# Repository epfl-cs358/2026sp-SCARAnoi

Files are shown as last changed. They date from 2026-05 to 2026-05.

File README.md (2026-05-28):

<p align="center">
  SCARAnoi logo
</p>

<p align="center">
  A SCARA robotic arm designed to solve the Tower of Hanoi using computer vision.
</p>

<p align="center">
  
  
  
  
</p>

# SCARA Arm - Solving Hanoi Tower

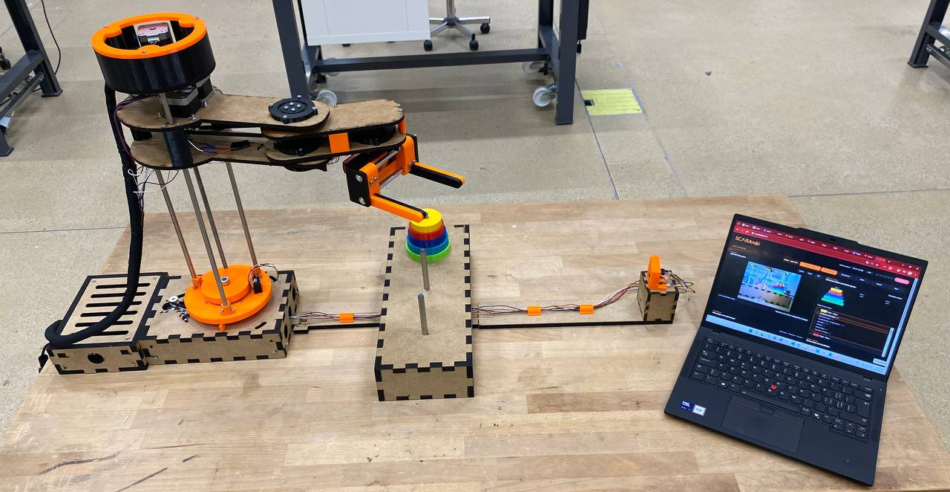
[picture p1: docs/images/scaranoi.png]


The SCARAnoi project aims to design and build a SCARA robot arm capable of solving the Tower of Hanoi problem using computer vision and autonomous manipulation.

The system combines a mechanically designed SCARA arm, a vertical motion axis, a parallel-jaw gripper, a Hanoi platform with three pegs and multiple disks, and a camera-based detection pipeline. The robot detects the position and size of the disks, determines the current configuration of the puzzle, computes the required sequence of moves, and executes the corresponding pick-and-place actions. It is designed to solve standard Tower of Hanoi configurations and to handle intermediate or non-standard configurations by recomputing the solution from the detected state.

Beyond the final demo, the project is meant to be reusable and extensible. The mechanical subsystems, perception pipeline, and motion control logic are separated as much as possible so that anyone can improve individual parts of the project without redesigning the entire system from scratch.

Enjoy building!

# Table of Contents

- [Autonomous Hanoi Solving](#autonomous-hanoi-solving)
- [How to Build](#how-to-build)
  - [Prerequisites](#prerequisites)
- [Hardware](#hardware)
  - [Base](#base)
  - [Arm](#arm)
  - [Gripper](#gripper)
  - [Hanoi Platform and Camera Support](#hanoi-platform-and-camera-support)
- [Electronics](#electronics)
- [Software](#software)
  - [Running the Interface](#running-the-interface)
  - [Browser Interface](#browser-interface)
  - [ESP32 Firmware](#esp32-firmware)
  - [Arduino Firmware](#arduino-firmware)
- [Motion](#motion)
  - [Shoulder and Elbow Motion](#shoulder-and-elbow-motion)
  - [Z-Axis Motion](#z-axis-motion)
  - [Gripper Motion](#gripper-motion)
  - [Homing and Limits](#homing-and-limits)
- [Computer Vision](#computer-vision)
- [Hanoi Algorithm](#hanoi-algorithm)
- [Autonomous Operation](#autonomous-operation)
- [Manual Control](#manual-control)
- [Full Mechanical BOM](#full-mechanical-bom)
- [Top contributors](#top-contributors)

# Autonomous Hanoi Solving

This video shows the SCARAnoi robot solving the Tower of Hanoi problem autonomously. The system detects the initial disk configuration, computes the sequence of moves, and commands the SCARA arm to pick and place the disks according to the rules of the puzzle.

[Demo video](https://youtu.be/Ctyt3jcGtlI)

# How to Build

## Prerequisites

Before starting the build, make sure you have access to the fabrication tools needed for both the mechanical structure and the electronics. SCARAnoi is not only a 3D-printed robot: it also uses laser-cut MDF parts, rods, bearings, belts, motors, wiring, and embedded electronics. A small mechanical workshop setup is therefore very useful.

### 3D Printer

A 3D printer is needed for most of the custom mechanical parts of the robot. This includes parts of the SCARA arm, the gripper frame, the racks and pinion, the jaw holders, the jaws, the Hanoi disks, pulley adapters, spacers, and other small mechanical interfaces.

Most of the 3D-printed parts of SCARAnoi were made in PETG. TPU was used only for the side contact pieces of the gripper jaws. These softer pieces improve contact with the disks and help prevent slipping during pick-and-place movements.

### Laser Cutter

A laser cutter is required for the flat MDF structure of the robot. 

Make sure the MDF thickness matches the design files. If the material thickness is different, the slots may become too loose or too tight and the assembly may need to be adjusted.

### Soldering Equipment

Soldering equipment is needed for the electrical part of the robot. The system includes stepper motors, limit switches, an ESP32-CAM, a servo motor, buck converters, an Arduino Mega, and a RAMPS 1.4 board.

Heat-shrink tubing, connectors, and proper cable management are strongly recommended to avoid loose contacts, short circuits, or communication issues between the ESP32 and the Arduino.

### Mechanical Tools

Basic mechanical tools are required for assembling and adjusting the robot. 

Some parts may need small manual adjustments after fabrication. For example, rods may need to be cut to length, holes may need to be cleaned, and bearings or shafts may need to be fitted carefully.

Pay special attention to the moving assemblies. The Z-axis rods, lead screw, shoulder rotation, belts, pulleys, and gripper racks should move smoothly without excessive friction. Small alignment errors can create noise, wobbling, or missed steps during motion.

### Drill

A drill is useful for preparing or adjusting holes in MDF and 3D-printed parts. 

Be careful when drilling 3D-printed parts. If a hole becomes too large, the part may no longer hold screws, rods, or bearings firmly.

### Computer

A laptop or desktop computer is required to program and control the system. It is used to flash the Arduino firmware, program the ESP32-CAM, run the computer vision code, use the manual control interface, and test the autonomous Hanoi solver.

# Hardware

The hardware of the SCARAnoi project is composed of a SCARA robot arm designed to solve the Tower of Hanoi problem. The system consists of a base, a two-segment arm, a gripper, and a Hanoi platform with camera support.
The structure is divided into four main mechanical assemblies:

- Base
- Arm
- Gripper
- Hanoi Platform and Camera Support

The full mechanical assembly is available here: [Full SCARAnoi assembly design](docs/CAD/Full-Assembly/FinalAssemblySCARAnoi.step).

## Base

Base full assembly : [Base-Assembly-STEP-file](docs/CAD/Base/Assembly/base-assembly.step)

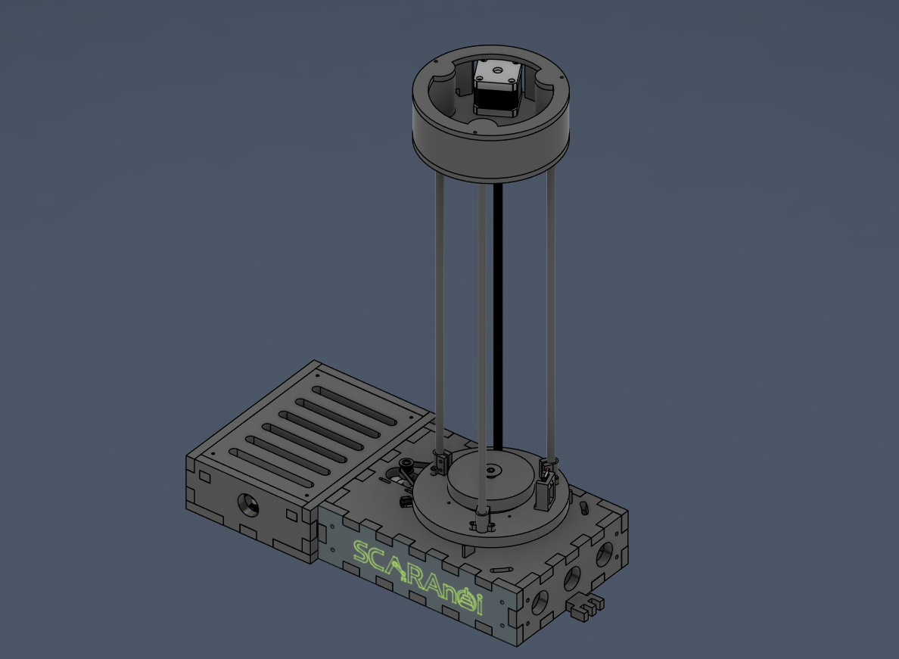
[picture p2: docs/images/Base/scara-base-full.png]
SCARA base full assembly


The base is the main structural support of SCARAnoi. It holds the vertical Z-axis mechanism, supports the rotating shoulder platform, and keeps the robot stable while the arm is moving.

The final version was redesigned as a laser-cut MDF structure with an attached electrical box. This box keeps the electronics accessible during debugging and integration, without needing to open the whole mechanical base every time.

The rotating shoulder platform is mounted on top of the moving Z-axis platform and forms the first rotational joint of the SCARA arm. It is driven by a GT2 belt transmission between a 20-tooth pulley and a 160-tooth pulley. This reduction increases the available torque at the shoulder, which is important because this joint carries the rest of the arm.

### Files to Laser Cut

- [Main base wide side plates x2](docs/CAD/Base/Laser-cut/SideBox-2.dxf)
- [Main base side plate x1](docs/CAD/Base/Laser-cut/SideBox-1.dxf)
- [Main base side plate attached to electrical box x1](docs/CAD/Base/Laser-cut/SideBoxH-1.dxf)
- [Main base top plate x1](docs/CAD/Base/Laser-cut/TopBox.dxf)
- [Main base bottom plate x1](docs/CAD/Base/Laser-cut/BotBox.dxf)
- [Electrical box side plates x2](docs/CAD/Base/Laser-cut/SideElec-2.dxf)
- [Electrical box side plate plug holes x1](docs/CAD/Base/Laser-cut/SideElec-PH.dxf)
- [Electrical box side plate attached to main base box x1](docs/CAD/Base/Laser-cut/SideElecH-1.dxf)
- [Electrical box cover x1](docs/CAD/Base/Laser-cut/TopElec.dxf)
- [Electrical box bottom plate x1](docs/CAD/Base/Laser-cut/BotElec.dxf)
- [Electrical box cover holders x4](docs/CAD/Base/Laser-cut/MountingElec-4.dxf)
- [Upper lift mounting plate x1](docs/CAD/Base/Laser-cut/ShoulderBase.dxf)

### Files to 3D Print

- [Shoulder platform x1](docs/CAD/Base/3D-print/Platform.stl)
- [Shoulder 160 teeths pulley x1](docs/CAD/Base/3D-print/Pulley160T.stl)
- [Shoulder platform cover x1](docs/CAD/Base/3D-print/Cover.stl)
- [Rod clamp supports x3](docs/CAD/Base/3D-print/SmoothRod_Clamp.stl)
- [Limit switch holder base x1](docs/CAD/Base/3D-print/SwitchHolderPlatform.stl)
- [Limit switch holder shoulder x1](docs/CAD/Base/3D-print/SwitchHolderShoulder.stl)
- [Upper lift assembly side panel x1](docs/CAD/Base/3D-print/UpperLiftSide.stl)
- [Upper lift assembly cover plate x1](docs/CAD/Base/3D-print/UpperLiftCover.stl)
- [Mounting blocks x8](docs/CAD/Base/3D-print/Mounting.stl)
- [Limit switch actuators x2](docs/CAD/Base/3D-print/LimitSwitchActuator.stl)

### Bill of Materials

| Part | Quantity | Specification / Notes |
|---|---:|---|
| Smooth rods | 3 | 8 mm diameter, 450 mm length |
| T8 lead screw | 1 | 8 mm diameter, 400 mm length |
| Axial ball bearings | 2 | 50 mm inner diameter, 70 mm outer diameter, 14 mm width |
| Deep groove ball bearing | 1 | 10 mm inner diameter, 30 mm outer diameter, 9 mm width |
| Deep groove ball bearing | 1 | 8 mm inner diameter, 22 mm outer diameter, 7 mm width |
| GT2 belt | 1 | 6mm width, 400 mm length |
| GT2 pulley | 1 | 20-tooth motor pulley (or 16 to have a perfect 1:10 ratio) |
| Shaft coupler | 1 | 5 mm to 8 mm |
| Nema-17 Stepper motor | 2 | For the Z-axis vertical motion and the shoulder rotation|
| MDF sheet 10mm| 1 | For the box |
| MDF sheet 6mm| 1 | For the NEMA motor mounting plate |
| M2.5, M3 and M4 screws | As needed | For mechanical attachments |
| M2.5, M3 and M4S Heat inserts | As needed | For mechanical attachments |
| M10 Screw, Nut and washer | 1 | For fixing the shoulder to the base |
| Limit switches | 4 | For homing the shoulder and Z axis |

### Assembly Procedure

<p align="center">
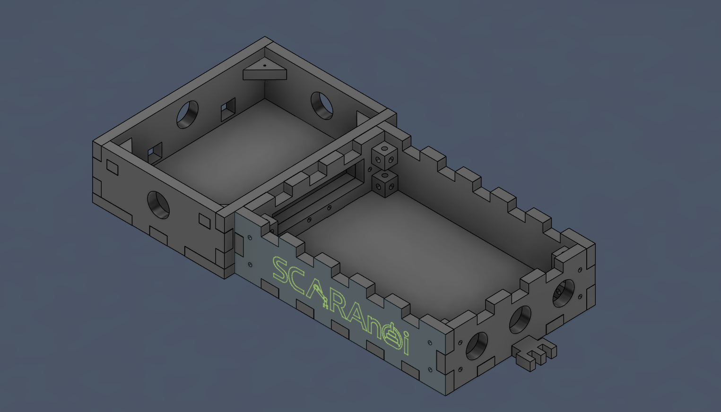
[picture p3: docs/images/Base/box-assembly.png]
Box assembly CAD
  
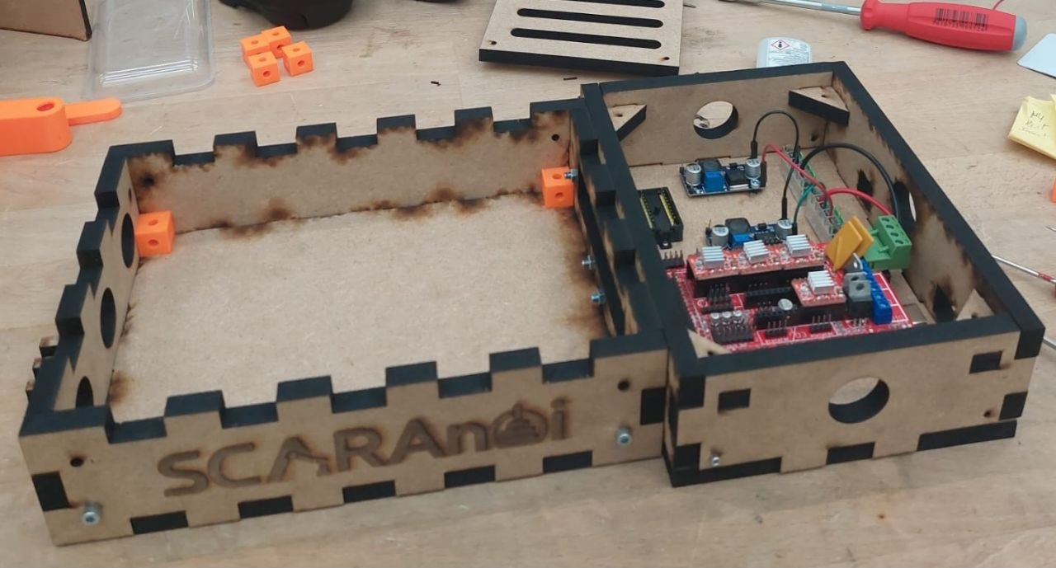
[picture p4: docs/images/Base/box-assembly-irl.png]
Box assembly in real life
  
</p>
Laser cut the MDF parts for the main base and the attached electrical box. Start by assembling the main SCARA base with the finger joints. This base should not be permanently sealed, since some internal parts may still need to be accessed later, for example to tighten the shoulder screw or rearrange wires going through it. To make the side panels removable, we used small 3D-printed mounting blocks inside the base corners. Each block contains two M4S heat-set inserts, one for each adjacent side panel. The blocks are glued to the inner face of a horizontal panel, and the side panels are screwed into them using M4×12 screws. This keeps the base rigid while still allowing it to be opened if needed.

The electrical box is assembled separately. Its side and bottom panels can be glued normally, since it remains accessible from its own opening. Once assembled, attach it to the main base using M4 screws. 

Do not install the top face of the main SCARA base yet. Keeping the top open makes it easier to mount the Z-axis motor, the shoulder platform, the belt transmission, and the screw/nut assembly. If the top face is installed too early, it will probably need to be removed again.

<p align="center">
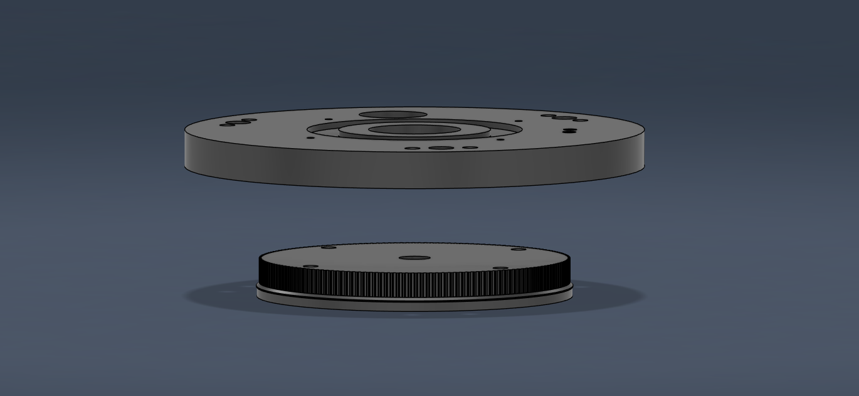
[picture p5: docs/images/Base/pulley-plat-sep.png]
Pulley platform separated
  
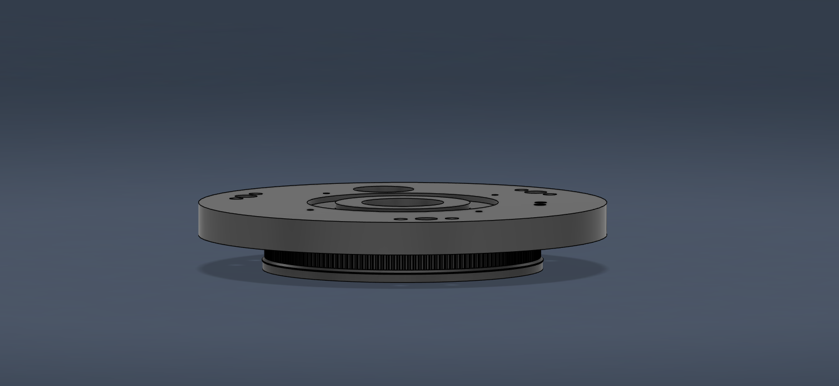
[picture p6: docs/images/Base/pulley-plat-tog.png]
Pulley platform assembled
  
</p> 
Attach the shoulder platform to the 160-tooth pulley using four M2.5×12 screws. The two parts were printed separately to make iteration easier: if one part has a defect or needs a design change, only that part has to be reprinted. Insert four M2.5 heat-set inserts into the pulley, then screw the pulley to the shoulder platform.

Insert two M3 heat-set inserts for each rod clamp into the shoulder platform, for a total of six inserts. Place the three rod clamps and attach them using M3×12 screws.

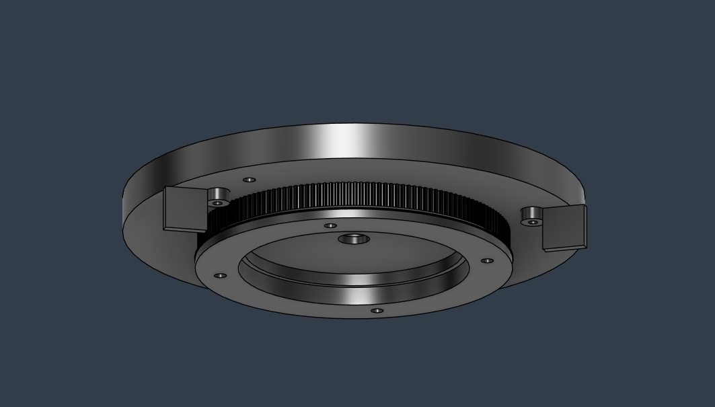
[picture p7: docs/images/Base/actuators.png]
Actuators


The insert holes for the rod clamps pass through the shoulder platform. Flip the platform and reuse two accessible holes to mount the limit switch actuators. Avoid the clamp located on the belt side. Insert the heat-set inserts from the opposite side, then attach the two actuators using one M3×12 screw each.

<p align="center">
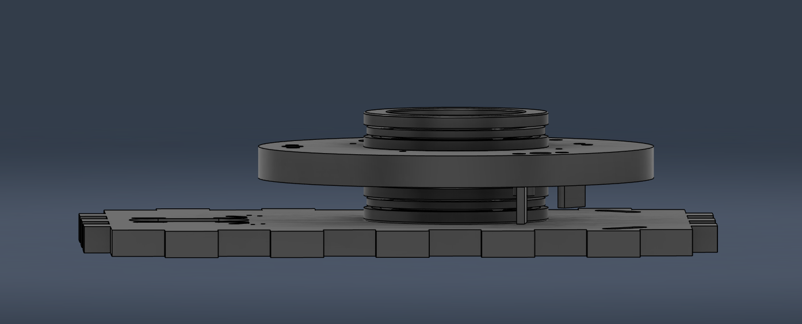
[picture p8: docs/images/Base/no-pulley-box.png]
Box without pulley system
  
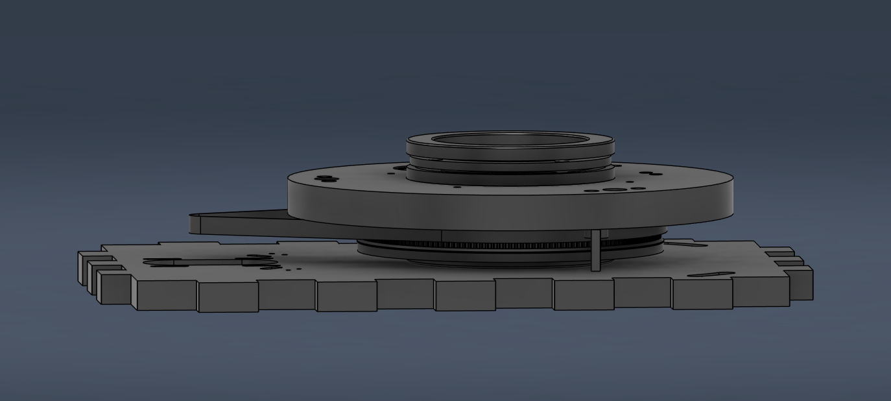
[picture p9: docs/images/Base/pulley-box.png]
Box with pulley system
  
</p>

Next, assemble the shoulder rotation stack. Place one axial ball bearing on the box top face, centered around the 10 mm hole. Before placing the shoulder platform, put the belt around the 160-tooth pulley so it is already in position for the belt transmission. Seat it then on the bearing, making sure the bearing fits correctly into the circular recess at the bottom of the pulley.

<p align="center">
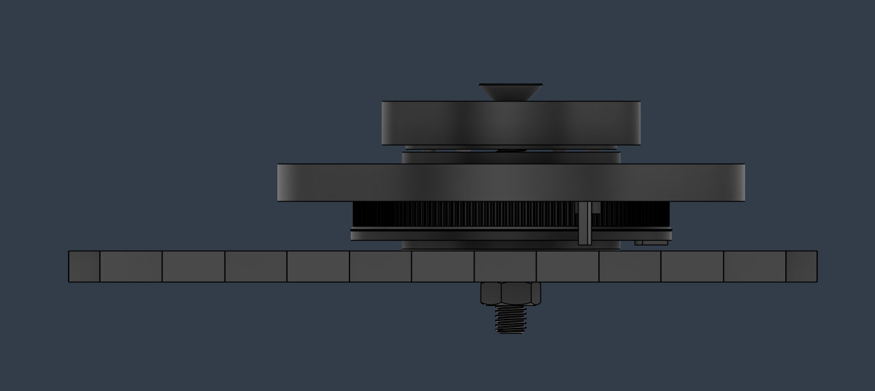
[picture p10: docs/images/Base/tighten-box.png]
Tightened box assembly
  
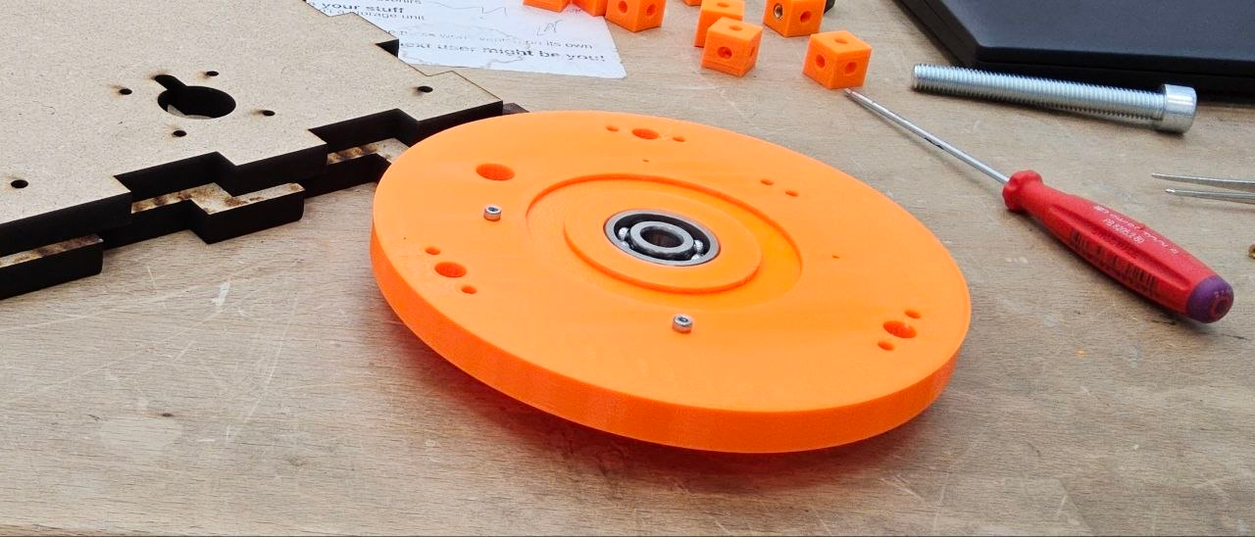
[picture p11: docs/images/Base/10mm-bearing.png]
10 mm bearing
  
</p>

Place the 10x30x9 ball bearing inside the hole at the center top of the platform, then place the second axial bearing in the circular recess on top of it and add the shoulder platform cover. Align the 10 mm holes of the shoulder platform, pulley, bearings, and base top face. Insert the M10 screw from the top, through the full stack, until it comes out under the base top face. Add the washer and M10 nut from below, then tighten carefully. The stack should have no excessive play, but the shoulder must still rotate freely without too much friction.

Once the shoulder stack is assembled, adjust the belt transmission. Place the shoulder NEMA motor in the slots of the base top face and attach the 20-tooth pulley to the motor shaft. Pass the belt around both pulleys, then slide the motor in the slots to set the belt tension. The belt should be tight enough to avoid skipping, but not so tight that it makes rotation difficult. When the tension is correct, fix the motor using four M3×12 screws.

Before closing the main base, it is better to install and wire the three limit switches. This can still be done later, but the top face would need to be removed again. Two limit switches are mounted directly on the main base using M2 screws and nuts. If the screws are not long enough, drill the mounting holes slightly deeper.

The third limit switch is mounted on the shoulder platform. First screw it to its holder using two M2 screws, then attach the holder to the shoulder platform using two M2.5 screws. For this, insert two M2.5 heat-set inserts into the corresponding holes in the shoulder platform. Route the limit switch wires through the nearest hole in the main base, then pass them together with the motor wires through the opening between the main base and the electrical box.

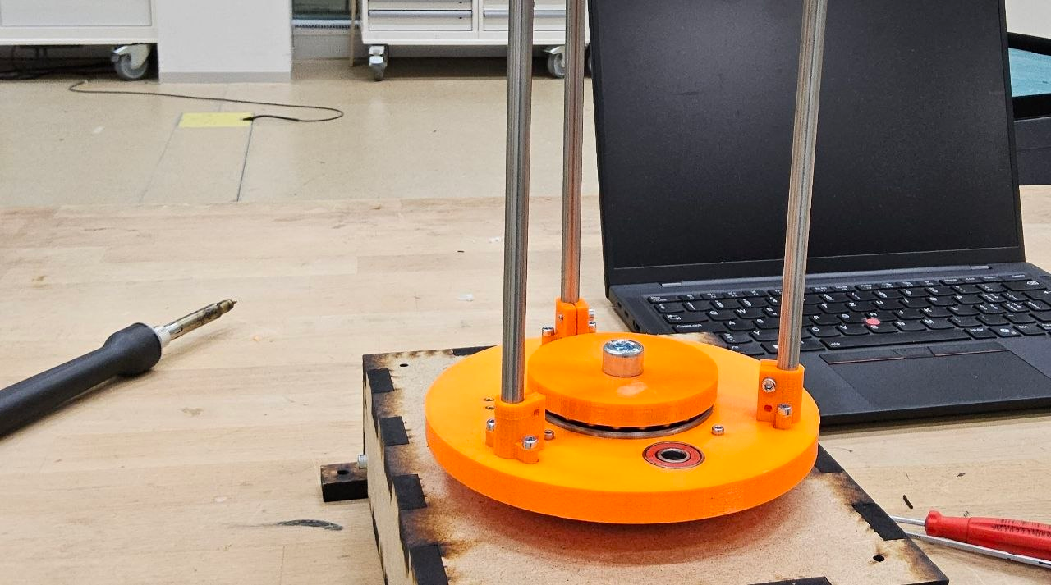
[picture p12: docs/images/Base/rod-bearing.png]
Rod bearing


After this, close the main SCARA base by installing the top face. Then install the three 8 mm smooth rods vertically. Place the 8x22x7 ball bearing into its matching hole in the platform, insert each rod into its clamp support and tighten it using two M3 screws. These rods guide the moving shoulder platform during Z-axis motion and prevent it from tilting, so they should be as parallel as possible. If they are misaligned, the platform may create friction or get stuck.

<p align="center">
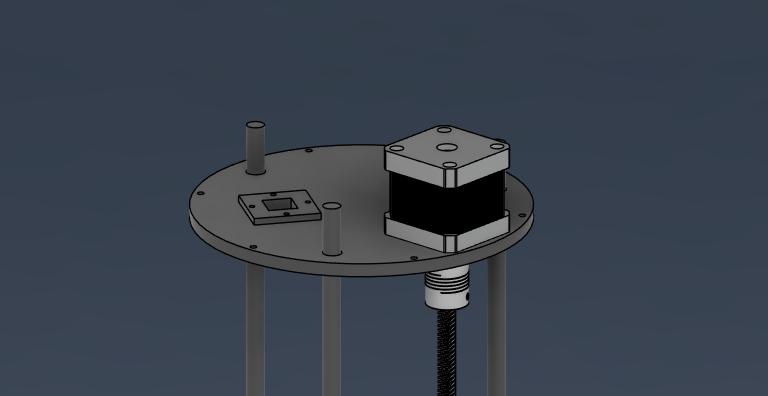
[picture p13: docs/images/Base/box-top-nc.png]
Box top without cover
  
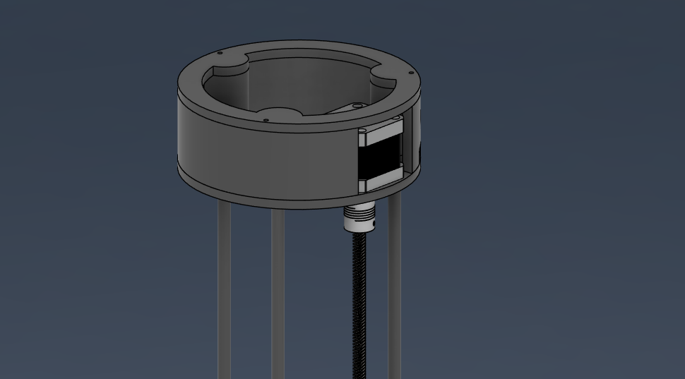
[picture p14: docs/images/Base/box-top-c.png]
Box top with cover
  
</p>

Next, assemble the upper lift. Insert M3 heat-set inserts into the top and bottom screw holes of the upper lift side panel. Screw the side panel to the 6 mm MDF upper lift mounting plate. Place the Z-axis NEMA motor in the corresponding slot, screw it in place, and attach the shaft coupler to the motor shaft. Then screw the upper lift cover plate to the top of the side panel.

Connect the T8 lead screw to the free side of the shaft coupler. Then place the 8x22x7 ball bearing into its matching hole in the platform, insert the three 8 mm smooth rods into their corresponding holes in the upper lift cover plate and finally guide the lead screw through the bearing. 

To mount the arm, the upper lift cover plate will need to be removed temporarily so the arm can be inserted onto the rods.

## Arm

Arm full assembly : [Arm-Assembly-STEP-file](docs/CAD/Arm/Assembly/arm-assembly.step)

The arm is the main kinematic structure of the SCARA robot. It consists of two rigid segments connected by rotational joints. Each joint is driven independently, giving the robot two degrees of freedom for horizontal motion. This allows the gripper to freely reach any object in a radius less than the combined length of the arms.<br>
- The floor and ceiling of each of the arm segments are made using laser-cut 6mm thick MDF. The rest of the parts are made using 3d-printed parts, they include bearing holders, bearing covers, pulleys and pillars.
- Each of the rotation axes (which we named Y for the elbow segment and E for the gripper) is supported by 2 bearings to ensure no undesirable play and proper transmission for the E rotation.
- Each rotation is also limited by 2 limit switches that have approximately an 80 degree angle between them. The effective dead zone can be tuned depending on the piece interfacing with the switches.
- Both rotation axes have a 3.2:1 pulley ratio. This can be changed by printing pulleys with more teeth or choosing the motor pulleys with less teeth.

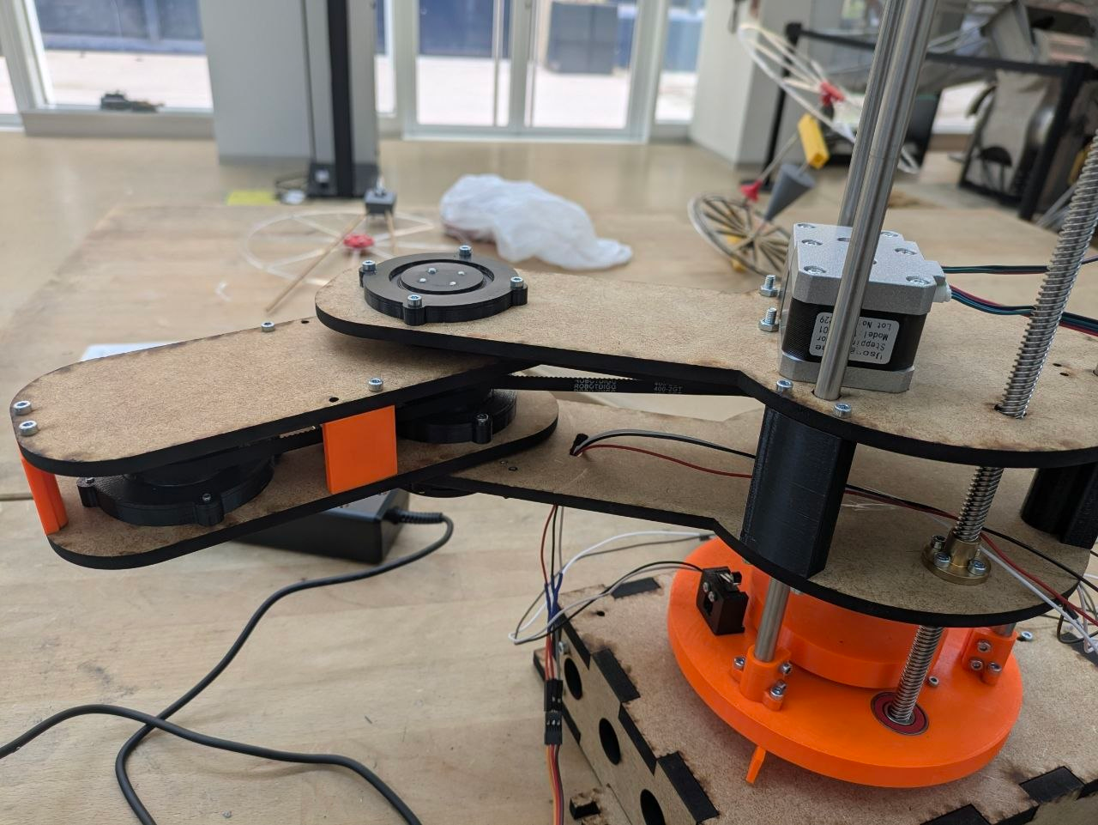
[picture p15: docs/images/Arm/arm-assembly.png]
Arm Assembly


### Files to Laser Cut

- [Inner arm ceiling](docs/CAD/Arm/Laser-cut/inner-arm/inner-ceiling.dxf)
- [Inner arm floor](docs/CAD/Arm/Laser-cut/inner-arm/inner-floor.dxf)
- [Motor holder](docs/CAD/Arm/Laser-cut/inner-arm/motor-holder.dxf)
- [Outer arm ceiling](docs/CAD/Arm/Laser-cut/outer-arm/outer-ceiling.dxf)
- [Outer arm floor](docs/CAD/Arm/Laser-cut/outer-arm/outer-floor.dxf)

### Files to 3D Print

#### Inner arm pieces

- [Inner arm cover 1](docs/CAD/Arm/3D-print/inner-arm/inner-cover1.stl)
- [Inner arm cover 2](docs/CAD/Arm/3D-print/inner-arm/inner-cover2.stl)
- [Inner arm cover 3](docs/CAD/Arm/3D-print/inner-arm/inner-cover3.stl)
- [Inner arm housing cover1](docs/CAD/Arm/3D-print/inner-arm/inner-housing-cover1.stl)
- [Inner arm housing cover2](docs/CAD/Arm/3D-print/inner-arm/inner-housing-cover2.stl)
- [Inner arm housing 1](docs/CAD/Arm/3D-print/inner-arm/inner-housing1.stl)
- [Inner arm housing 2](docs/CAD/Arm/3D-print/inner-arm/inner-housing2.stl)
- [Inner pillar 1](docs/CAD/Arm/3D-print/inner-arm/inner-pillar1.stl)
- [Inner pillar 2](docs/CAD/Arm/3D-print/inner-arm/inner-pillar2.stl)
- [Inner pillar 3](docs/CAD/Arm/3D-print/inner-arm/inner-pillar3.stl)
- [Inner pulley](docs/CAD/Arm/3D-print/inner-arm/inner-pulley.stl)

#### Outer arm pieces

- [Outer arm cover 1](docs/CAD/Arm/3D-print/outer-arm/outer-cover1.stl)
- [Outer arm cover 2](docs/CAD/Arm/3D-print/outer-arm/outer-cover2.stl)
- [Outer arm housing cover1](docs/CAD/Arm/3D-print/outer-arm/outer-housing-cover1.stl)
- [Outer arm housing cover2](docs/CAD/Arm/3D-print/outer-arm/outer-housing-cover2.stl)
- [Outer arm housing 1](docs/CAD/Arm/3D-print/outer-arm/outer-housing1.stl)
- [Outer arm housing 2](docs/CAD/Arm/3D-print/outer-arm/outer-housing2.stl)
- [Outer pillar 1](docs/CAD/Arm/3D-print/outer-arm/outer-pillar1.stl)
- [Outer pillar 2](docs/CAD/Arm/3D-print/outer-arm/outer-pillar2.stl)
- [Outer pillar 3](docs/CAD/Arm/3D-print/outer-arm/outer-pillar3.stl)
- [Outer pulley 1](docs/CAD/Arm/3D-print/outer-arm/outer-pulley1.stl)
- [Outer pulley 2](docs/CAD/Arm/3D-print/outer-arm/outer-pulley2.stl)

### Other Parts

| Part | Quantity | Specification / Notes |
|---|---:|---|
| NEMA 17 stepper motors | 2 | 17hs4401  |
| GT2 aluminium Timing pulley| 2 | 20 Teeth |
| M3 Threaded heat inserts | 12 |  |
| Deep Groove Ball Bearing 6906 / 61906 RS | 4 | 30x47x9mm |
| GT2 6mm wide Timing belt | 2 | 400m long |
| GT2 6mm wide Timing belt | 1 | 350m long |
| LM8UU Linear Bearing | 4 | 8mm |
| TR8 Trapezoidal Nut Brass | 1 | 8mm pitch |

### Assembly Procedure

- Screw the motor holder to the inner arm ceiling using M4 screws and nuts. Then mill the housing holes in the inner arm floor with a drill and milling head, for the purpose of using countersunk screws. Also drill the holes of the microswitch holes about 2mm down (unless you can get M2 screws longer or equal to 14mm).<br>
- For each of the bearings, insert them inside the housing and then put the housing cover on top, then screw these assemblies to their corresponding floor or ceiling. Beware that the lower bearing assembly is upside down and screwed with countersunk screws. Make sure you get the right housing for the bearings, the outer arm housings are slightly taller than the inner arm housings. Also for the assembly with the double pulley, you need to put together the cover pieces of the inner arm first as told next.<br>
- The outer arm ceiling holes that interface with the inner arm need to be drilled to allow the screw heads to fit in, otherwise they rub against the outer arm first pulley, which can prevent the arm from moving slowly. <br>
- Once that is done, you can now screw together the pieces sandwitching the bearings. The inner cover 1 and inner pulley go on the top inner bearing, the inner cover 2 and inner cover 3 go on the bottom inner bearing (they can be held together with friction from the screw fitting in the petg). The outer pulley 2 and outer cover 2 go on the furthest outer bearing, and the outer pulley 1 and outer cover 1 go on the closest outer bearing. This last one has to be screwed with the bearing assembly mentioned earlier.<br>
- Try to put the motor pulley on the second motor shaft only about 10mm in to be aligned with the height of the outer arm pulley. After that try to connect the with a 400mm belt, it might be easier to put the belt around the motor pulley then sliding into the pulley. You can then move the motor to attain desired tightness, then screw it down. <br>
- Finally, you can put heat inserts in the holes of inner and outer pillars. And screw everything where it fits.<br>
- I advise to have the CAD open to check the position of each piece in the full assembly. Some pieces might seem identical but they are not.<br>

## Gripper

Gripper full assembly : [Gripper-Assembly-STEP-file](docs/CAD/Gripper/Assembly/gripper-assembly.step)

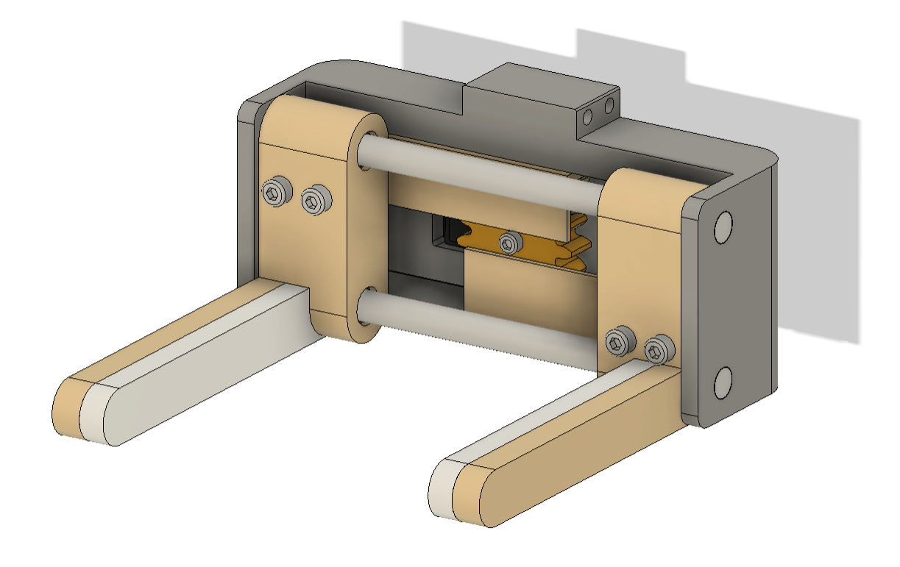
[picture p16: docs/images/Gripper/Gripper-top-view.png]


The gripper is the end-effector (“hand”) of the SCARA arm. It is designed to grasp, hold, transport, and release the Tower of Hanoi disks.

The selected system is a parallel-jaw gripper actuated by a rack-and-pinion mechanism. This design allows both jaws to move symmetrically, which helps keep the disks centered during grasping.

### Files to Laser Cut

No laser-cut parts are required for the gripper.

### Files to 3D Print (using the default PrusaSlicer settings unless specified otherwise)

- [Gripper frame](docs/CAD/Gripper/3D-print/PETG/Frame.stl)
- 2 racks & 1 pinion: [Right Rack](docs/CAD/Gripper/3D-print/PETG/Right-Rack.stl), [Left Rack](docs/CAD/Gripper/3D-print/PETG/Left-Rack.stl), [Pinion](docs/CAD/Gripper/3D-print/PETG/Pinion.stl); Print settings: Vertical Shells > Perimeters = 5
- 2 jaws: [Right Jaw](docs/CAD/Gripper/3D-print/PETG/Right-Jaw.stl), [Left Jaw](docs/CAD/Gripper/3D-print/PETG/Left-Jaw.stl)
- 2 TPU contact layers with disks: [Right-Jaw TPU Layer](docs/CAD/Gripper/3D-print/TPU/TPU-Layer-Right-Jaw.stl), [Left-Jaw TPU Layer](docs/CAD/Gripper/3D-print/TPU/TPU-Layer-Left-Jaw.stl); Print settings: Horizontal Shells > Solid Layers > Top = 0, Bottom = 4 / Infill = 25%

### Other Parts

| Part | Quantity | Specification / Notes |
|---|---:|---|
| DS3230MG servo motor | 1 |  |
| Aluminium guide rods | 2 | 8 mm diameter, 14 cm length |
| LM8UU linear bearings | 4 | 8 mm × 12 mm × 19 mm |
| M4 screws and inserts | 4 each | To attach jaws to racks |
| M3 screws and inserts | 4 each | To attach gripper frame to arm |
| Metallic retaining rings | 4 | 8 mm diameter, serves as an additional safety measure to prevent the rods from sliding out of the frame |

### Assembly Procedure

1) 3D print the main frame, racks, pinion, and jaws in PETG, and print the 2 jaw contact layers in TPU.
2) Glue each TPU contact layer onto its corresponding inner jaw surface using high-strength adhesive.
3) In each jaw, insert 2 LM8UU linear bearings into the dedicated mounting holes.
4) Now that the jaws are ready to be mounted, place the M4 threaded inserts into the dedicated holes of the racks and into the mounting holes at the back of the frame.
5) Mount the servo motor at the rear of the frame using M4 screws.
6) Install the 2 racks inside the internal guiding channels of the frame. Ensure they slide smoothly (lightly sand the channels if needed).
7) Glue the plastic servo hub into the pinion.
8) Now that the servo hub and pinion are attached together, mount the servo hub onto the servo shaft while properly aligning the pinion teeth with the teeth of both racks.
9) Actuate the servo to verify that both racks move symmetrically in opposite directions.
10) Machine circular grooves at both ends of each aluminum guide rod to allow later the 4 retaining rings to be attached securely.
11) Insert the 2 aluminum guide rods through one side only of the frame.
12) Slide both jaws onto the rods through their linear bearings, then pass the rods through the opposite side of the frame.
13) Now make sure that the jaws slide smoothly along the guide rods without excessive friction.
14) Fasten each jaw to its corresponding rack using M4 screws. The inner surfaces of the jaws should remain perfectly parallel to ensure stable and firm gripping of the disks.
15) Attach the 4 metallic retaining rings, one on each side of both rods.
16) Now that the gripper is assembled, test gripping each of the 5 disks with the servo actuated. Verify that the gripper opens sufficiently for the largest disk while still securely gripping the smallest one.
17) Place the 4 M3 threaded inserts into the dedicated mounting holes in the gripper’s top rectangular extrusion.
18) Mount the gripper onto the arm by fitting the rectangular extrusion into the dedicated 3D-printed arm interface and fastening it with M3 screws.

The final assembly should look as follows (with the retaining rings attached on both sides):

<p align="center">
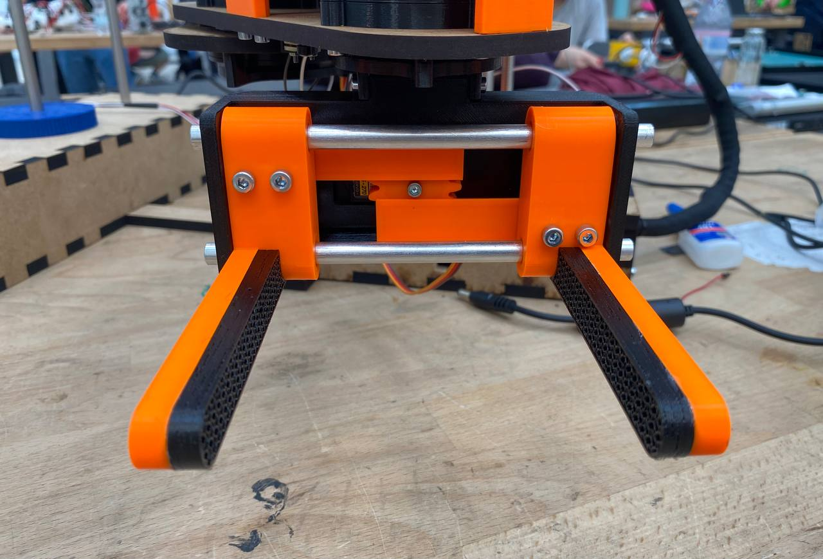
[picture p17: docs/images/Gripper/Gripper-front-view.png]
  
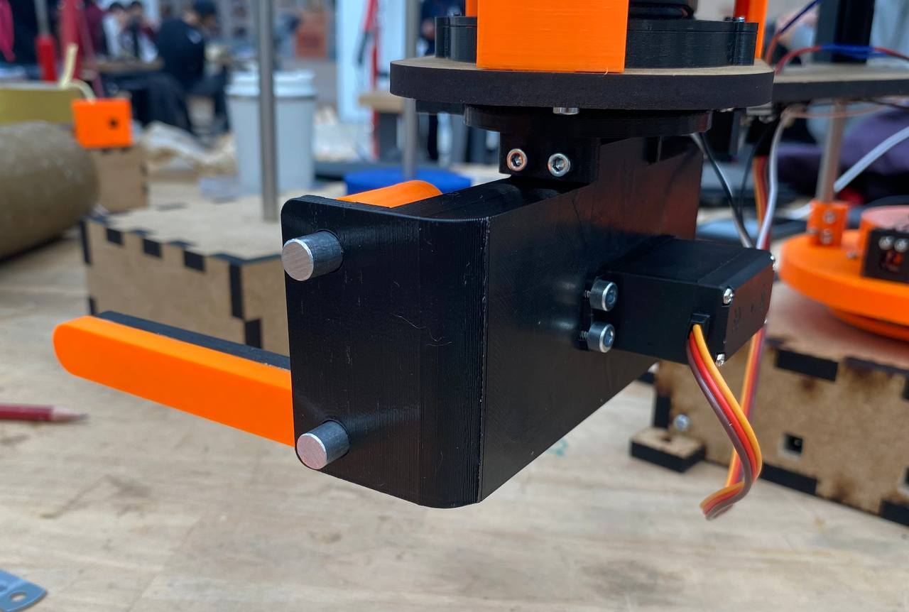
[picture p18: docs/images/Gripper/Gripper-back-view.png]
  
</p>

<p align="center">
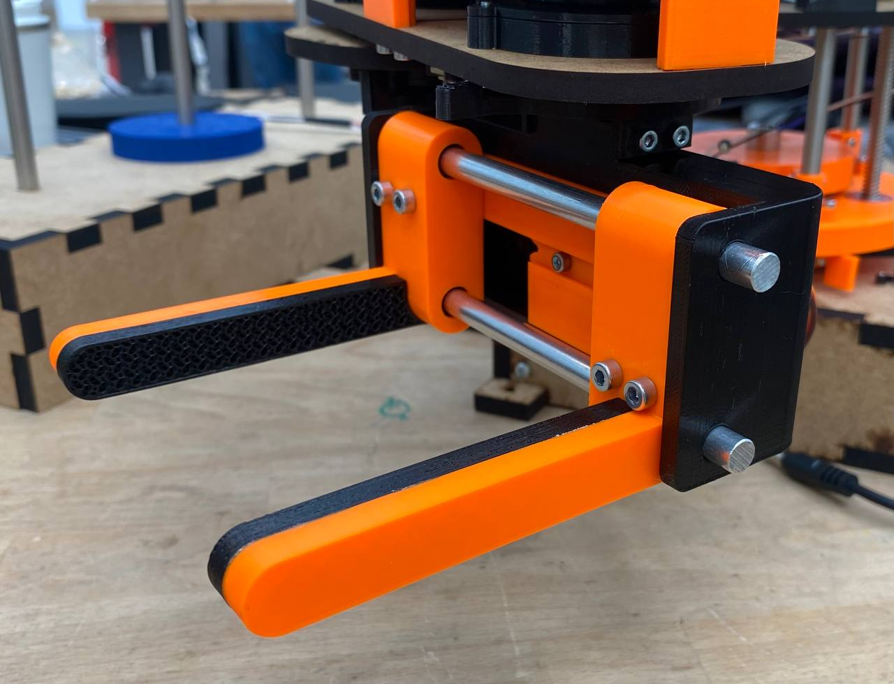
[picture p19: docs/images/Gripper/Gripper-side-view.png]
  
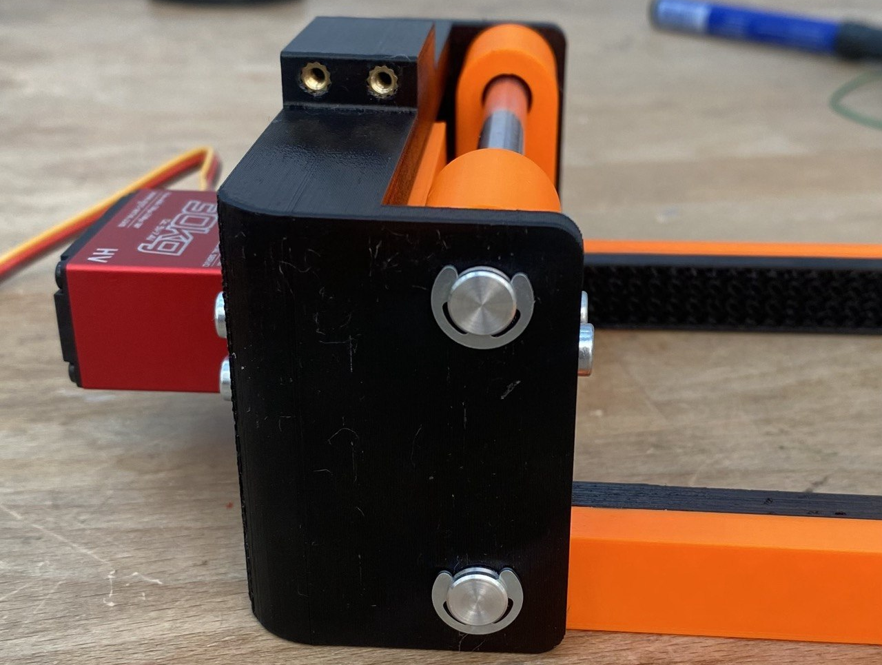
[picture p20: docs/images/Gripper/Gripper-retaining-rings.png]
  
</p>

## Hanoi Platform and Camera Support

Hanoi Platform and Camera Support full assembly : [Full-Assembly-STEP-file](docs/CAD/Hanoi-Platform-Camera-Support/Assembly/HanoiPlatformandCameraSupport.step)

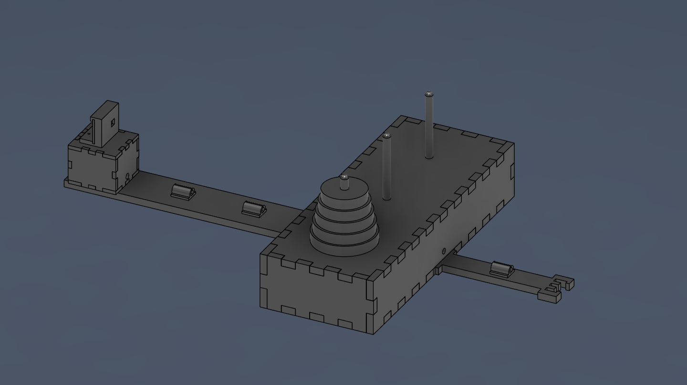
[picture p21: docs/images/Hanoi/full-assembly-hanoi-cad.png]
full assembly hanoi


The Hanoi platform is the working environment of the robot. It holds the three pegs and the disks manipulated by the SCARA arm.

A camera support structure is integrated into the platform to provide a fixed overhead view of the puzzle. This fixed viewpoint helps the computer vision system detect the disk configuration more reliably.

### Files to Laser Cut

- Main Hanoi platform: [Top Box Face](docs/CAD/Hanoi-Platform-Camera-Support/Laser-cut/TopHanoiBox.dxf), [Bottom Box Face](docs/CAD/Hanoi-Platform-Camera-Support/Laser-cut/BottomHanoiBox.dxf), [Big Side Box Face x2](docs/CAD/Hanoi-Platform-Camera-Support/Laser-cut/BigSideHanoiBox.dxf), [Small Side Box Face x2](docs/CAD/Hanoi-Platform-Camera-Support/Laser-cut/SideSmallHanoiBox-2.dxf)
- Camera support box: [Top/Bottom Box Face](docs/CAD/Hanoi-Platform-Camera-Support/Laser-cut/TopBoxCamera-2.dxf), [Side Box Face with no cable holes x2](docs/CAD/Hanoi-Platform-Camera-Support/Laser-cut/SideFaceCameraNH.dxf), [Side Box Face with cable holes x2](docs/CAD/Hanoi-Platform-Camera-Support/Laser-cut/SideFaceCameraH-2.dxf)
- 2 box connectors: [Connector Scara-Hanoi](docs/CAD/Hanoi-Platform-Camera-Support/Laser-cut/LiaisonHanoi-Box.dxf), [Connector Hanoi-Camera](docs/CAD/Hanoi-Platform-Camera-Support/Laser-cut/LiaisonCamera-Hanoi.dxf)

### Files to 3D Print

- 5 Hanoi disks: [Disk 1](docs/CAD/Hanoi-Platform-Camera-Support/3D-print/Disks/Disk1.stl), [Disk 2](docs/CAD/Hanoi-Platform-Camera-Support/3D-print/Disks/Disk2.stl), [Disk 3](docs/CAD/Hanoi-Platform-Camera-Support/3D-print/Disks/Disk3.stl), [Disk 4](docs/CAD/Hanoi-Platform-Camera-Support/3D-print/Disks/Disk4.stl), [Disk 5](docs/CAD/Hanoi-Platform-Camera-Support/3D-print/Disks/Disk5.stl)
- Camera case: [Body](docs/CAD/Hanoi-Platform-Camera-Support/3D-print/Pegs/peg-head-body.stl), [Slider](docs/CAD/Hanoi-Platform-Camera-Support/3D-print/Camera/esp_slider.stl)
- Peg heads x3: [Body](docs/CAD/Hanoi-Platform-Camera-Support/3D-print/Pegs/peg-head-body.stl), [Top](docs/CAD/Hanoi-Platform-Camera-Support/3D-print/Pegs/peg-head-top.stl)
- [Cable Holder](docs/CAD/Hanoi-Platform-Camera-Support/3D-print/Box/cable_management.stl)

### Other Parts

| Part | Quantity | Specification / Notes |
|---|---:|---|
| Rods | 3 | 10 mm diameter, 8 mm inner diameter, used as pegs  |
| ESP32-CAM module | 1 |  |
| M3 Screws| As needed |  |
| MDF sheet| As needeed | We used 2, 10 mm for the hanoi box and connectors and 5mm for the camera box, but dimensions don't really matter|

### Disk Dimensions

The system uses 5 disks. Each disk has a height of 15 mm and a central hole of 14 mm diameter. The disk diameters range from 53 mm to 90 mm.

| Disk number | Diameter |
|---|---|
| 1, smallest | 59 mm |
| 2 | 66 mm |
| 3 | 73 mm |
| 4 | 80 mm |
| 5, largest | 87 mm |

### Assembly Procedure

Laser cut the main platform and the camera support structure from MDF. Assemble the platform using the joints.

Install the three pegs into the platform. The pegs should be spaced 90 mm apart from center to center. Make sure that they are vertical and firmly fixed.

3D print the 5 disks. Each disk should slide freely on the pegs without excessive friction. The 14 mm central hole provides clearance around the 10 mm pegs.

Mount the camera case to its support box, which is itself mounted at the end of the Hanoi-camera connector. This connector keeps the ESP32-CAM at a fixed position relative to the Hanoi pegs, which improves repeatability during computer vision detection.

There are no predefined screw holes in the camera support box so that the camera angle can be adjusted manually during assembly and once the desired angle is found, the screw holes can be drilled directly in the box. Verify that all three pegs and the full disk area are visible in the camera frame.

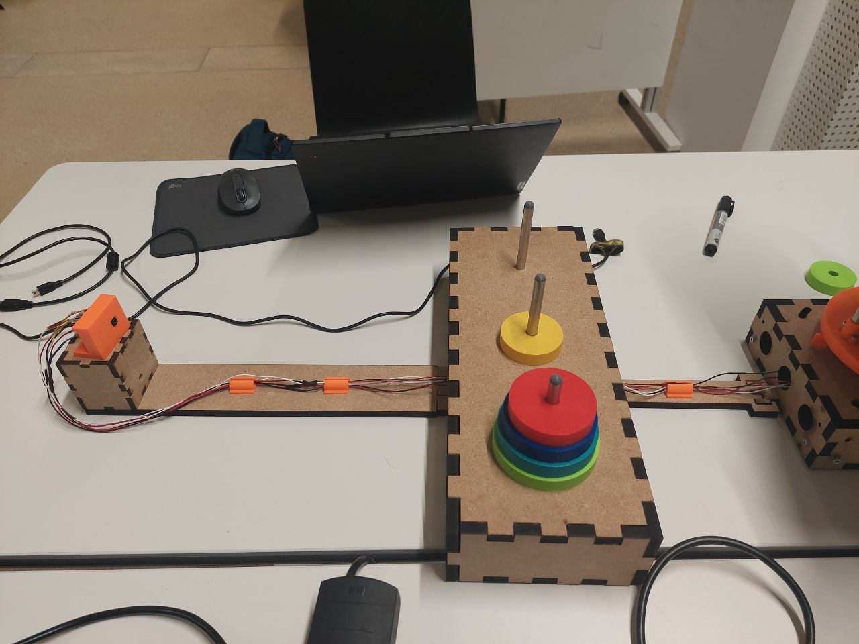
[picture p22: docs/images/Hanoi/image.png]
Hanoi image


# Electronics

The entire system uses a 12V 10A DC power supply, which is plugged into a standard barrel jack. This jack is then wired to two connectors that distribute the power and regroup the common ground for three components: the RAMPS 1.4 board and two LM2596 buck converters. The buck converters are calibrated to regulate 5V and 7V for the EPS32-CAM and DS3230MG servo motor respectively.

The system is centered around an Arduino Mega 2560 with a RAMPS 1.4 board. The port of the Arduino is made accessible in order to upload code to it, while the RAMPS sits on top of it and handles all connections to other components. This includes the four A4988 stepper drivers, the cable to the NEMA 17 stepper motors themselves, the eight limit switches, the servo motor and the 8-channel logic-level converter. This converter is then connected to the ESP32-CAM to allow the serial communication with the Arduino/RAMPS system.

<p align="center">
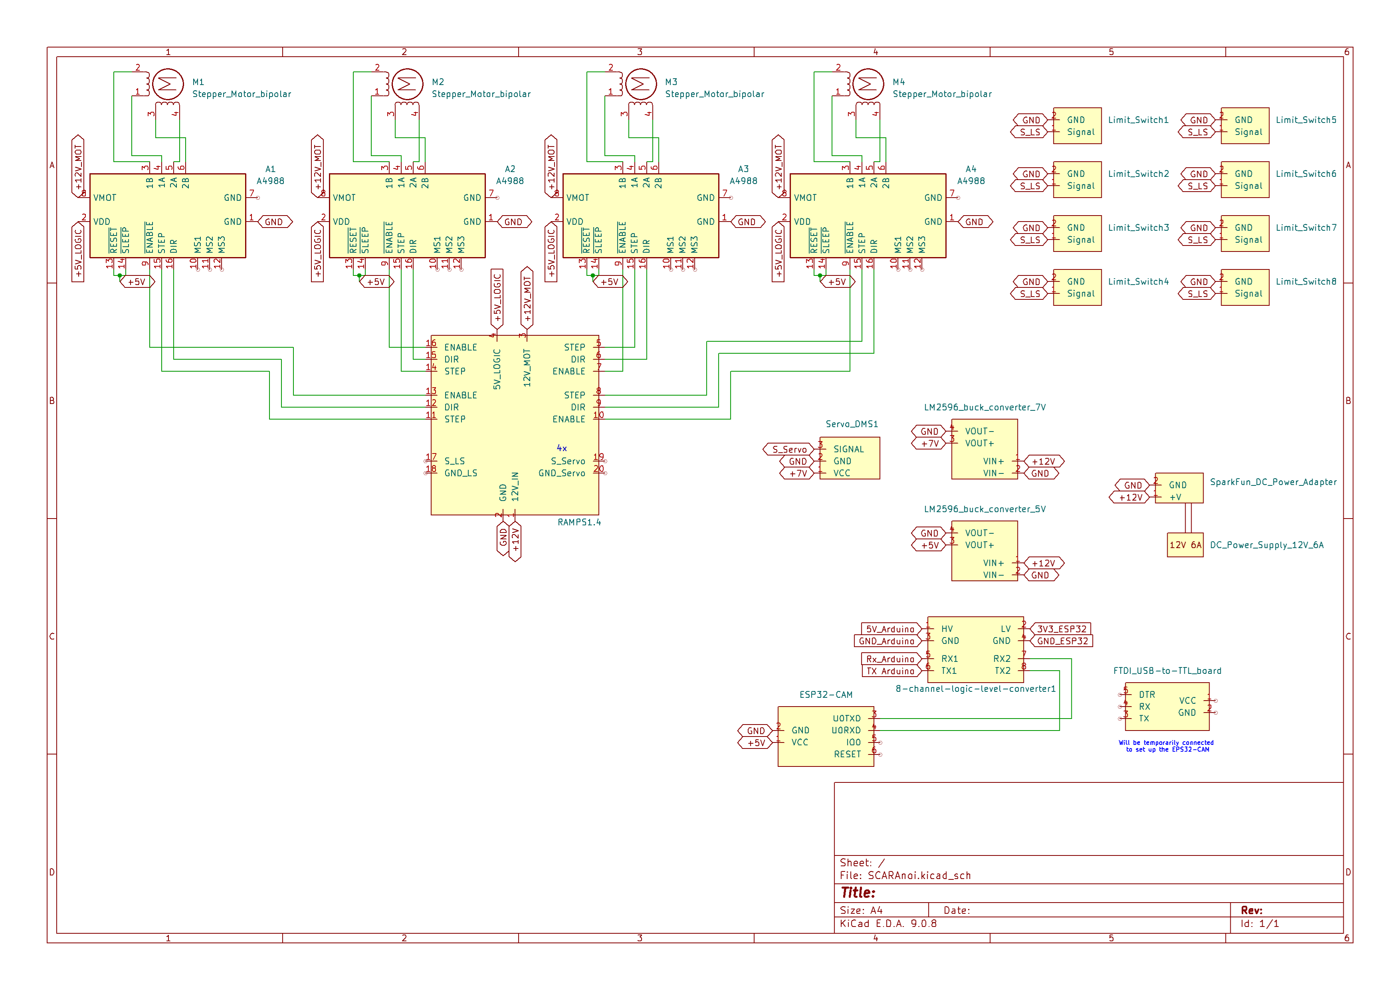
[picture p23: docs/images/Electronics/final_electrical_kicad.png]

</p>

### Full Electrical BOM

| Item | Quantity |
|---|---:|
| 12V, 10A DC power supply | 1 |
| Standard DC barrel jack | 1 |
| LM2596 buck converters | 2 |
| Arduino Mega 2560 | 1 |
| RAMPS 1.4 board | 1 |
| A4988 stepper drivers | 4 |
| NEMA 17 stepper motors | 4 |
| DS3230MG servo motor | 1 |
| Limit switches | 8 |
| ESP32-CAM | 1 |
| 8-channel logic-level converter | 1 |
| FTDI USB-to-TTL adapter for programming the ESP32-CAM | 1 |
| Mini USB-B to USB-A cable | 1 |
| Connectors | 2 |
| Wires, heat-shrink tubing | Multiple |

### Assembly Procedure

Start by gluing the barrel jack (to which you have soldered wires) to the right hole when looking at the electrical box from behind the arm (the left hole is the one where the holes for the Arduino Mega are). You can use a hot glue gun for this. Make sure that it’s accessible with the plug when the box is closed and that it’s stable enough to endure a lot of plugs and un-plugs. 

Prepare the buck converters by calibrating them and soldering pins to each in/out, +/- hole. Measure out and cut the cables you want to use for the connections.

Next, fix the RAMPS/Arduino and buck converters to the box by first gluing some small plastic spacers directly over each hole that will act as nuts for the M3 screws, which will then secure the components into place. For the logic converter, you can choose how to fix the 3D-printed holder to the box. A good option is to drill 1.5 mm holes and use small wood screws to secure it.

<p align="center">
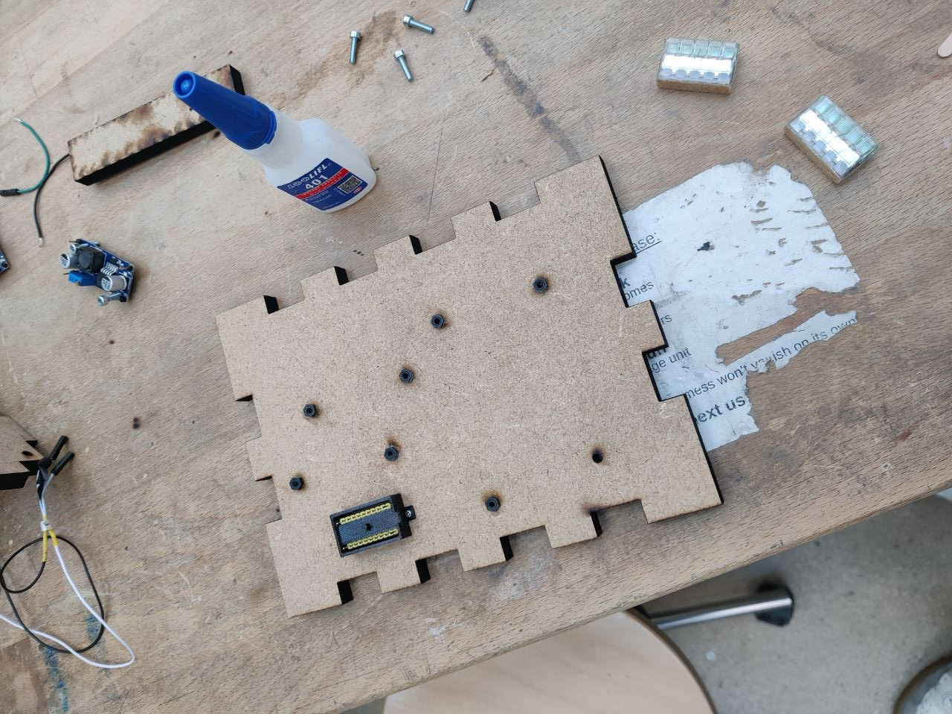
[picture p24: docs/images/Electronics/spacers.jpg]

</p>

You can now connect all wires from the two connectors.

After calibrating them, insert the A4988 drivers into the appropriate driver slots and verify their orientation before powering the board. Connect the NEMA 17 motors to the RAMPS motor outputs. Check the coil wiring carefully to avoid incorrect motor behavior.

Next prepare all limit switches by soldering a signal wire (S) to the NO pin of each switch, and a ground wire (GND) to the C pin of each switch. The other end of the wire should have a female connector pin (this can be soldered too). You can then mount them on each designated spot using M2 screws and nuts. Connect the limit switches to the RAMPS inputs. There are only six designed slots, but one can use the S and GND pins of remaining servo slots on the RAMPS and repurpose them in the firmware. 

Connect the servo motor to the dedicated 7 V buck converter, and connect the third signal wire to the designated slot on the RAMPS. Do not power the servo directly from the Arduino 5 V rail.

Connect the ESP32-CAM to the dedicated 5 V buck converter, and to the logic converter (RX/TX communication and 3V3/GND for reference). Then connect the logic converter to the RAMPS. Use the FTDI adapter for programming the EPS32-CAM. Again, do not power the servo directly from the Arduino 5 V rail.

Before powering the full system, verify all voltage rails with a multimeter:
- 12 V main input
- 7 V servo supply

<p align="center">
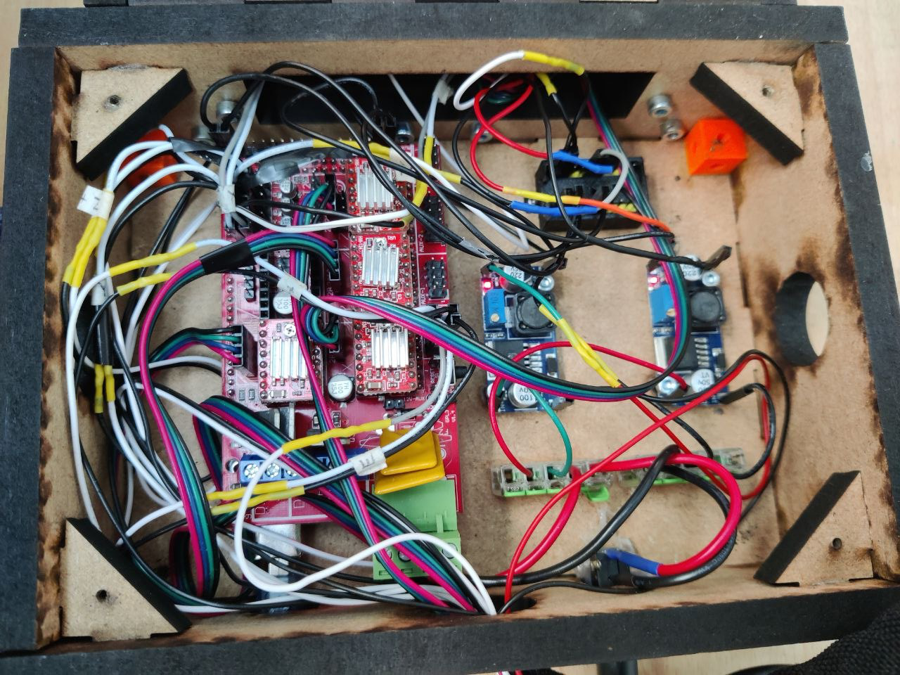
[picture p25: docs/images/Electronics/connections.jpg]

</p>

# Software

The software is split into three main parts. The browser interface is used to control the robot, preview the camera feed, detect the Hanoi state, run the solver, execute the move sequence, and display command feedback. The ESP32-CAM acts as the Wi-Fi, camera, and serial bridge. The Arduino Mega, connected to the RAMPS 1.4 board, runs the low-level firmware that moves the motors.

```text
software/
├── index.html                  # Main browser interface
├── style.css                   # Interface styling
├── app.js                      # Manual control, workspace graph, command sending, UI logic
├── config.js                   # ESP32 IP, robot dimensions, command mapping, timing settings
├── hanoi-solver.js             # Hanoi state validation, solver, move queue, CV checks, error detection
├── cv_server.py                # Flask/OpenCV bridge for camera processing and detection
├── detectDisque.py             # Disk detection using OpenCV and HSV color masks
├── requirements.txt            # Python dependencies
├── esp32.ino                   # ESP32-CAM HTTP bridge and camera stream
├── command-descriptions.json   # Command descriptions shown in the UI tooltips
└── custom-firmware/
    └── custom-firmware.ino     # Arduino Mega + RAMPS custom motion firmware
    └── axis-center.ino         # Axis center calibration helper
```

## Running the Interface

The browser interface is served by the local Python server. This server also handles the OpenCV processing, so the computer vision does not need to run directly inside the browser.

To install the Python dependencies:

```bash
cd software
pip install -r requirements.txt
```

To start the interface and connect it to the ESP32:

```bash
python cv_server.py --esp-ip <ESP32_IP>
```

Then open:

```text
http://localhost:5000
```

The ESP32 IP can also be changed directly from the interface.

## Browser Interface

<p align="center">
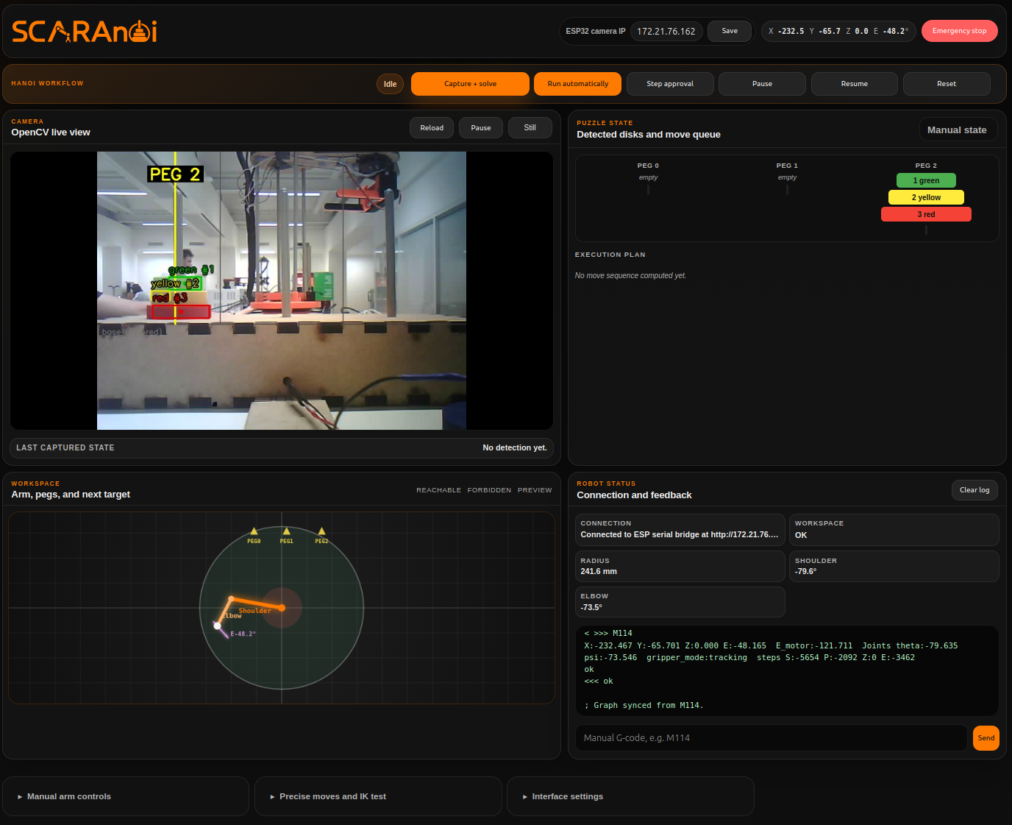
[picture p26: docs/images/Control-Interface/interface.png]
Main interface
  
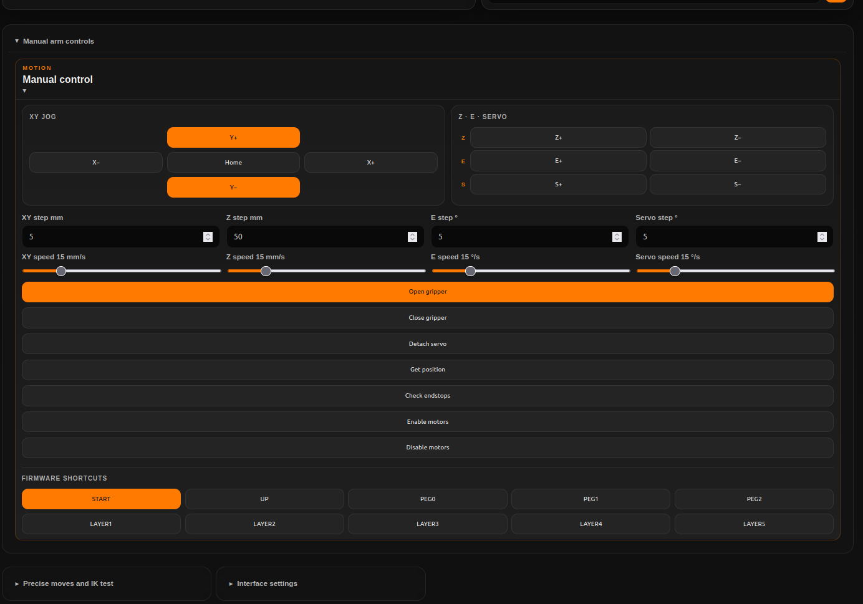
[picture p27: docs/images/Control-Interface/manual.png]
Manual control interface
  
</p>

The browser interface is the main control panel of the robot. It provides manual arm control, absolute position control, camera preview, Hanoi state detection, solver controls, and command logs.

Commands are sent from the browser to the ESP32 using HTTP. The ESP32 then forwards them to the Arduino Mega through serial communication. This keeps the browser independent from the motor control details: the interface decides what command should be sent, while the firmware handles how the robot actually moves.

The interface also includes a top-down workspace graph. It shows the reachable area of the SCARA arm, the forbidden inner zone, the peg positions, and the current estimated position of the end effector. When the firmware returns a position with `M114`, the interface uses it to resync the graph with the real robot state.

## ESP32 Firmware

The ESP32-CAM is used as the bridge between the browser interface and the Arduino Mega. It receives HTTP requests from the interface, forwards the commands to the Arduino over UART, and sends the Arduino response back to the browser. It also provides the camera stream used by the OpenCV server.

The firmware is located in:

```text
software/esp32.ino
````

The ESP32 exposes these main endpoints:

```text
/send?msg=<command>   Send one or more commands to the Arduino
/capture              Capture one still image from the ESP32-CAM
:81/stream            MJPEG camera stream
```

For example, this sends an `M114` position request to the Arduino:

```text
http://<ESP32_IP>/send?msg=M114
```

In the current setup, the ESP32 connects to an existing Wi-Fi network and communicates with the Arduino Mega at baud rate `250000`.

## Arduino Firmware

The Arduino Mega is the low-level motion controller. It is connected to the RAMPS 1.4 board with A4988 stepper drivers. The firmware is custom-made for SCARAnoi and is located in:

```text
software/custom-firmware.ino
```

This firmware implements a smaller Marlin-like command set that is easier to adapt to our SCARA arm and to the specific movements needed for the Hanoi demo.

The firmware controls four axes:

* `X`: shoulder joint
* `Y`: elbow joint
* `Z`: vertical lift
* `E`: wrist / gripper rotation

The normal movement commands use Cartesian `X/Y` coordinates. Internally, the firmware uses inverse kinematics to convert these coordinates into the shoulder and elbow angles needed by the motors. The `Z` axis is controlled in millimeters, and the `E` axis is treated as a logical gripper angle.

The firmware also supports direct joint movement with `M360`. In that case, `X` and `Y` are interpreted as joint angles in degrees instead of Cartesian coordinates. This is useful for calibration, testing, and moving the robot without using inverse kinematics.

The gripper rotation has two orientation modes:

```text
M361 S0    Independent mode: the gripper keeps a fixed world direction
M361 S1    Tracking mode: the gripper stays fixed relative to the elbow
M361       Report the current gripper mode
```

In normal `G0` / `G1` movements, the firmware automatically computes the required raw `E` motor angle from the logical gripper angle and the selected gripper mode.

The firmware also includes custom text commands for the Hanoi demo:

```text
START      Move to the configured start pose, then move above the current peg
PEG0       Move above peg 0
PEG1       Move above peg 1
PEG2       Move above peg 2
UP         Move to the safe height above the current peg
LAYER1     Move down to layer 1
LAYER2     Move down to layer 2
LAYER3     Move down to layer 3
LAYER4     Move down to layer 4
LAYER5     Move down to layer 5
OPEN       Open the gripper
CLOSE1     Close the gripper using the layer 1 close angle
CLOSE2     Close the gripper using the layer 2 close angle
CLOSE3     Close the gripper using the layer 3 close angle
CLOSE4     Close the gripper using the layer 4 close angle
CLOSE5     Close the gripper using the layer 5 close angle
SPEED      Print the current movement speed
```

These macros keep the browser logic simpler. The browser only has to decide the logical Hanoi move, while the exact peg coordinates, Z heights, movement speeds, and gripper angles are stored in the firmware.

Common firmware commands include:

```text
G0 / G1 X.. Y.. Z.. E.. F..    Move to a position
G4 P..                         Pause for a given time in milliseconds
G28 [X] [Y] [Z] [E]            Home all axes or only selected axes
G90                            Use absolute positioning
G91                            Use relative positioning
G92 X.. Y.. Z.. E..            Set the current logical position

M17                            Enable all motors
M17 X / Y / Z / E              Enable selected motors only
M18 / M84                      Disable all motors
M18 X / Y / Z / E              Disable selected motors only

M92 X.. Y.. Z.. E..            Set steps per unit in RAM
M203 X.. Y.. Z.. E..           Set max axis speeds in RAM
M211 S0 / S1                   Disable or enable software limits

M112                           Emergency stop
M999                           Clear emergency stop

M114                           Report current position
M119                           Report endstop states
M400                           Wait for motion to complete
M503                           Print firmware settings

M280 P0 S..                    Move the gripper servo to an angle
M281 O..                       Set the gripper open angle in RAM
M282 P0                        Detach the servo

M360 X.. Y.. Z.. E.. F..       Direct joint move without SCARA inverse kinematics
M361                           Report gripper orientation mode
M361 S0                        Set independent gripper mode
M361 S1                        Set tracking gripper mode
```

# Motion

The motion system is based on a SCARA arm with a vertical lift and a servo gripper. A complete disk transfer consists of moving above a peg, going down to the correct disk layer, closing the gripper, lifting the disk, moving to another peg, and releasing it.

The firmware uses blocking movements. This means that a command finishes before the next movement command is processed. During motion, the firmware still checks for `M112`, so an emergency stop can interrupt a long movement.

The motors are enabled only when needed and are disabled again after movement. This avoids leaving the motors powered when nothing is moving.

## Shoulder and Elbow Motion

The shoulder and elbow joints control the horizontal position of the gripper above the Hanoi platform. For normal movements, the user gives target `X/Y` coordinates through the interface. The firmware then computes the corresponding SCARA angles using inverse kinematics.

This makes manual control easier because the user can think in terms of positions above the board, rather than individual motor angles.

For testing and calibration, the firmware also supports direct joint movement with `M360`. In this mode, `X` and `Y` are not Cartesian coordinates. They are directly interpreted as shoulder and elbow joint angles in degrees.

Example:

```text
M360 X10 Y-5 Z0 E0 F3000
```

This moves the shoulder by `10` degrees, the elbow by `-5` degrees, keeps `Z` unchanged, keeps the logical gripper angle unchanged, and uses feed value `3000`.

## Z-Axis Motion

The Z-axis moves the gripper up and down. It is used to approach a disk, grab it, lift it above the pegs, and lower it again at the target position.

For the Hanoi demo, the firmware stores predefined Z heights:

```text
Z_UP       Safe height above the pegs
LAYER1     First disk layer
LAYER2     Second disk layer
LAYER3     Third disk layer
LAYER4     Fourth disk layer
LAYER5     Fifth disk layer
```

This avoids recalculating the vertical position in the browser for every move. The interface can simply send commands such as `UP` or `LAYER3`.

The `PEG0`, `PEG1`, and `PEG2` commands first move the robot up to the safe height, then move horizontally above the selected peg. This reduces the risk of hitting the disks or pegs during side movements.

## Gripper Motion

The gripper is controlled by a servo motor. During the Hanoi sequence, the browser sends `OPEN` or one of the `CLOSE` commands, and the firmware moves the servo to the configured angle.

The close angle is split by disk layer:

```text
CLOSE1
CLOSE2
CLOSE3
CLOSE4
CLOSE5
```

This allows the gripper to close with different angles depending on the disk size or layer being handled.

For manual testing, the servo can also be controlled directly using:

```text
M280 P0 S<angle>
```

The command:

```text
M282 P0
```

detaches the servo when needed.

## Homing and Limits

Before running a full Hanoi sequence, the robot should be homed with:

```text
G28
```

This gives the robot a known reference position. The firmware can also home only selected axes:

```text
G28 X
G28 Y
G28 Z
G28 E
```

The firmware uses endstops with `INPUT_PULLUP`. With a normally-open switch wired between signal and ground, the triggered state is `LOW`.

Software limits can be enabled or disabled using:

```text
M211 S1    Enable software limits
M211 S0    Disable software limits
```

During normal movement, the firmware can also stop the robot if an enabled endstop is triggered unexpectedly.

Useful debug commands are:

```text
M119    Check endstop states
M114    Check current position
M503    Print firmware settings
```

After homing, the interface should request the current position again with `M114` so the workspace graph matches the firmware state.

# Computer Vision

<p align="center">
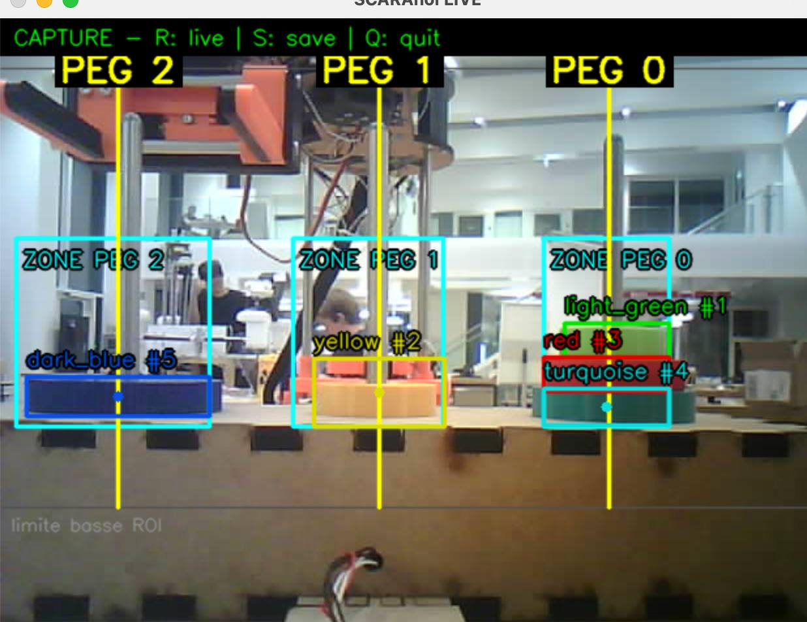
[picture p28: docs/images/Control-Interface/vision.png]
Computer Vision
  
</p>

The computer vision pipeline runs on the Python server.

```text
ESP32-CAM stream → cv_server.py → detectDisque.py → annotated stream + JSON state
```

The browser displays the annotated OpenCV stream from the local server. 

The main files are:

```text
software/cv_server.py
software/detectDisque.py
```

The OpenCV server provides:

```text
/              Browser interface
/cv-stream     Annotated MJPEG stream
/cv-snapshot   Latest annotated frame
/detect        Latest detected Hanoi state as JSON
/set-esp       Update the ESP32 stream IP
/health        Debug/status endpoint
```

`detectDisque.py` uses manual peg zones and HSV color masks. The search is restricted to configured rectangles around the three pegs, which reduces false detections from the robot or background.

The current peg convention is:

```text
Peg 0 = right
Peg 1 = middle
Peg 2 = left
```

The current disk convention in the detection code is:

```text
1 = yellow
2 = red
3 = dark blue
4 = turquoise
5 = light green
```

The detected state is returned as three peg lists, ordered from bottom to top.

Example:

```text
[[5, 4, 3], [], []]
```

The annotated stream also draws the ROI limits, peg zones, peg labels, and detected disk boxes.

# Hanoi Algorithm

The Hanoi solver is implemented in:

```text
software/hanoi-solver.js
```

It takes the detected or manually entered Hanoi state and computes the sequence of legal moves needed to solve the puzzle. The solver also supports partial setups, so it does not always require all five disks to be present.

The state is represented as three peg lists. Each disk is represented by its number, where smaller numbers are smaller disks. For example:

```text
Peg 0: [5, 4, 3]
Peg 1: []
Peg 2: []
```
The solver supports partial setups. It does not assume that all five disks are always present. The target peg can also be selected from the interface. If no valid target is selected, the code falls back to the configured target behavior.

Before solving, the state is checked to make sure it is legal. This prevents cases such as duplicate disks or a larger disk being placed on top of a smaller one.

Once the logical sequence is computed, each move is converted into firmware commands. A typical disk transfer follows this structure:

```text
Move above source peg
Go down to the source layer
Close the gripper
Move up
Move above target peg
Open the gripper
```

The browser can execute the sequence step by step with confirmation, or run it automatically one move after another. After each disk transfer, the system uses computer vision to compare the detected Hanoi state with the expected state. If they do not match, the sequence stops so the user can check the robot, the disks, or the camera detection before continuing.

# Autonomous Operation

The autonomous workflow combines camera detection, Hanoi planning, and robot execution.

The intended workflow is:

1. Start the ESP32-CAM bridge
2. Start the Python OpenCV server
3. Open the browser interface
4. Home the robot with `G28`
5. Detect the current Hanoi state
6. Compute the move sequence
7. Execute each disk transfer through the ESP32 bridge
8. Verify the state after each move
9. Continue until the puzzle is solved

The system can stop if the firmware does not acknowledge a command, if the detected state does not match the expected state, or if the user pauses the execution. This makes the autonomous mode safer during testing, especially while the camera detection is still being tuned.

## Error Detection

[Demo video](https://www.youtube.com/watch?v=a2-W_I98xwk)

photo_5818816066673642886_w

We also wanted the interface to be usable as a small interactive Hanoi game, not only as an automatic solver. The idea is that a player can try to solve the Tower of Hanoi manually, while the system uses the camera to check whether each move is correct.

In this mode, the player moves one disk by hand and then asks the interface to verify the board. The interface captures the current state with the OpenCV detection, compares it with the next state expected by the solver, and reports whether the move was valid.

If the move is correct, the player can continue. If the move is wrong, the interface stops the game and shows that the current board does not match the expected state. The player can then either fix the board manually or ask the robotic arm to correct the mistake when the error can be reversed safely.

The same verification mechanism is also used during automatic execution. After the robot moves a disk, the camera checks that the board actually changed as expected. If the detected state is different from the expected one, the sequence pauses instead of continuing with a wrong board state.

# Manual Control

Manual control is used for testing, calibration, and debugging. It is also useful when checking if the ESP32, Arduino, motors, endstops, and gripper are communicating correctly.

The interface supports:

- XY jogging
- Z up and down movement
- Wrist rotation
- Servo open and close
- Absolute position moves
- Manual command sending
- Homing
- Position sync
- Endstop checks
- Emergency stop

The manual interface also shows command logs and firmware responses. This helps debug problems such as a disconnected ESP32, a missing Arduino response, an endstop problem, or a move being rejected by the firmware limits.

## Full Mechanical BOM

| Item | Quantity |
|---|---:|
| GT2 closed timing belt of length 350 mm | 1 |
| GT2 closed timing belt of length 400 mm | 3 |
| GT2 20T, 6 mm belt, 5 mm bore Pulley | 3 |
| TR8 Trapezoidal Nut Brass Pitch 8mm | 1 |
| TR8 400mm trapezoidal threaded spindle Pitch 8mm | 1 |
| Linear bearings 8mm | 8 |
| 8mm/5mm Flexible Aluminium Coupling with Dowel Screws | 1 |
| Deep Groove Ball Bearing 6200 2RS 10x30x9 mm | 4 |
| Deep Groove Ball Bearing 6906 / 61906 RS 30x47x9 mm | 1 |
| Miniature Deep Groove Ball Bearing 608 2RS 8x22x7 mm | 1 |
| Axial ball bearing 51110 50x70x14 mm | 2 |

# Top contributors:

This project was made by:

- Rania Hida ([@Rania5724](https://github.com/Rania5724))
- Mehdi Belhaj ([@mehdi754-hub](https://github.com/mehdi754-hub))
- Youssef Benhayoun Sadafi ([@youssef-9511](https://github.com/youssef-9511))
- Ozan Esref Sahingöz ([@ozan-sz](https://github.com/ozan-sz))
- Jonathan Nilsson Pilemand ([@JonathanPilemand](https://github.com/JonathanPilemand))
- Maha El Qabli ([@melqabli](https://github.com/melqabli))
- Davood Hashimi ([@Davood-H](https://github.com/Davood-H))

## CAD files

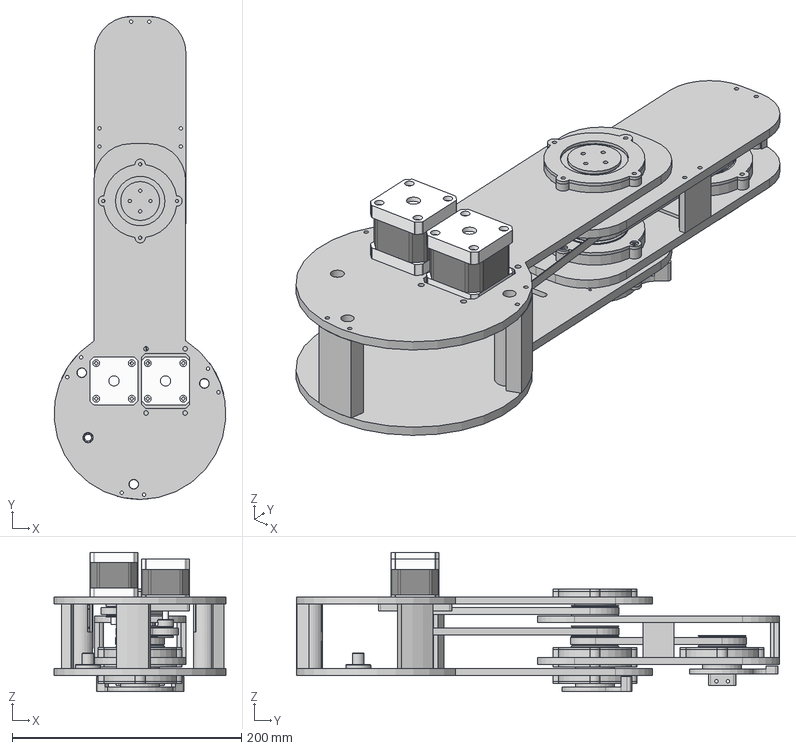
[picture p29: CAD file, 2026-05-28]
docs/CAD/Arm/Assembly/arm-assembly.step
149.7 x 421.4 x 121.5 mm
5972K293_Steel Ball Bearing x 4

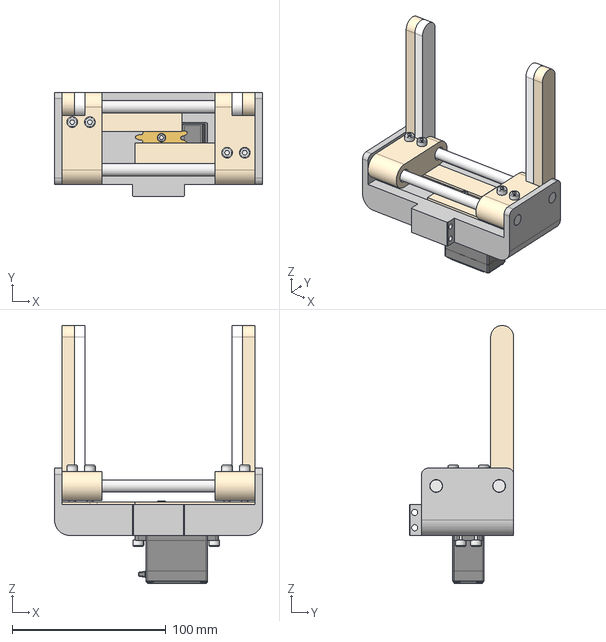
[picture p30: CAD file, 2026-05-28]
docs/CAD/Gripper/Assembly/Gripper-Assembly.step
135.5 x 68.0 x 168.0 mm

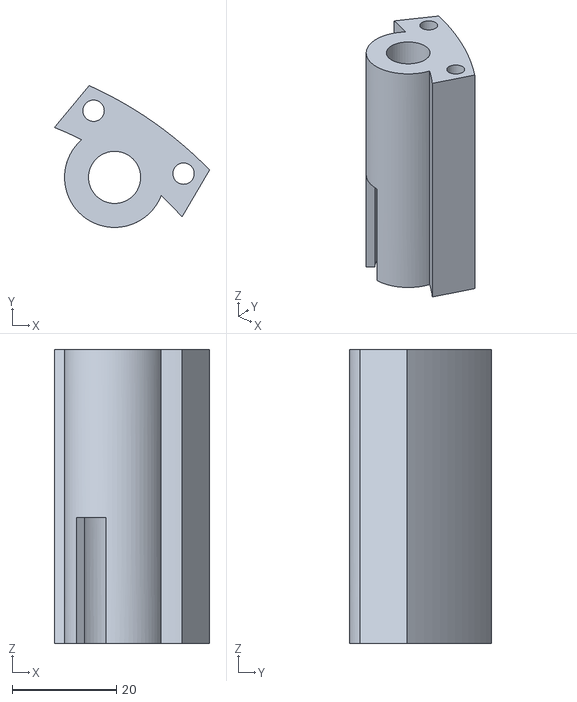
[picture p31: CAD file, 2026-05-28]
docs/CAD/Arm/3D-print/inner-arm/inner-pillar2.stl
29.8 x 27.2 x 56.4

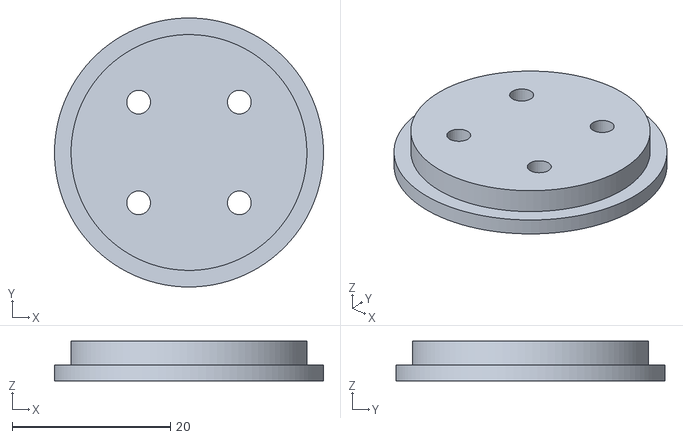
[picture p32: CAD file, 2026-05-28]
docs/CAD/Arm/3D-print/outer-arm/outer-cover1.stl
34.0 x 34.0 x 5.00

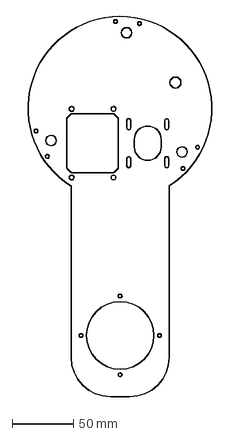
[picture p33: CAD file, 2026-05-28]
docs/CAD/Arm/Laser-cut/inner-arm/inner-ceiling.dxf
162.6 x 310.5 mm

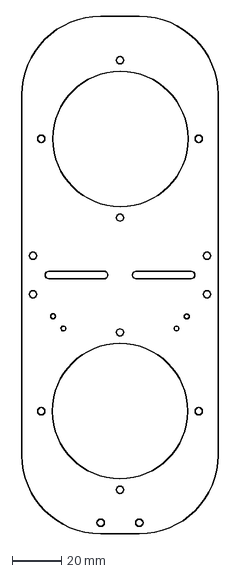
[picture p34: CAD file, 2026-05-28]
docs/CAD/Arm/Laser-cut/outer-arm/outer-floor.dxf
80.0 x 211.0 mm

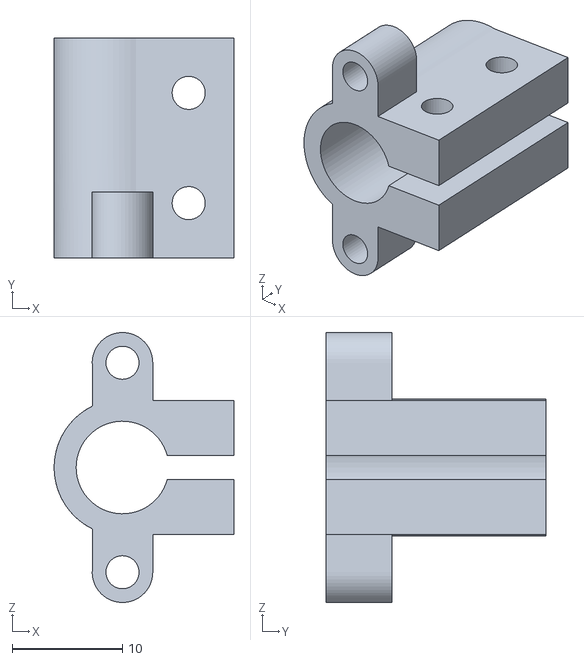
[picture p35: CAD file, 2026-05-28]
docs/CAD/Base/3D-print/SmoothRod_Clamp.stl
16.3 x 20.0 x 24.5

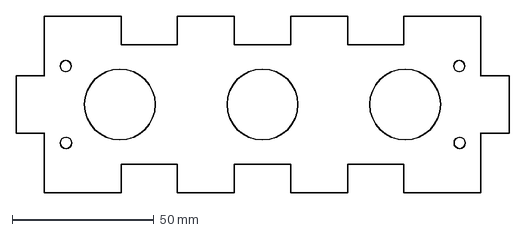
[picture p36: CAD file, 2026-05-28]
docs/CAD/Base/Laser-cut/SideBox-1.dxf
174.2 x 62.2 mm

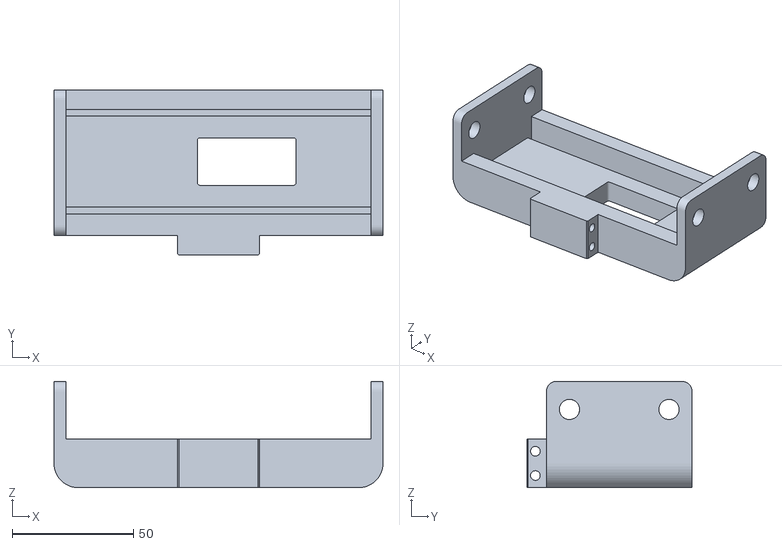
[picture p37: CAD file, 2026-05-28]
docs/CAD/Gripper/3D-print/PETG/Frame.stl
135.5 x 68.0 x 43.8

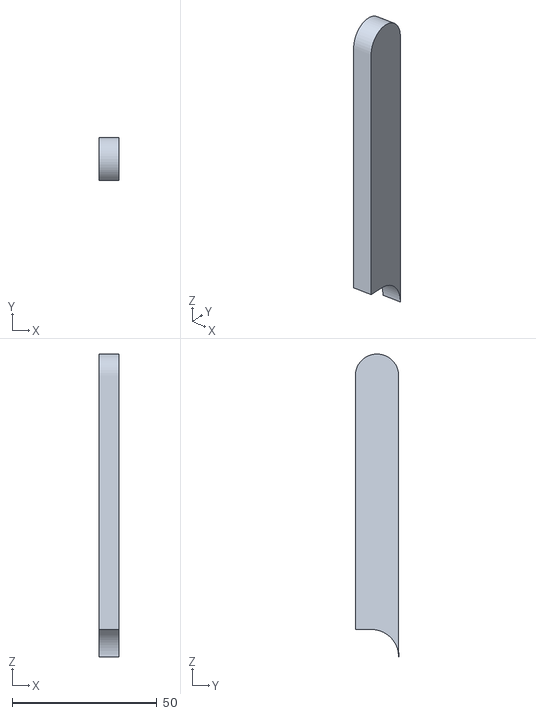
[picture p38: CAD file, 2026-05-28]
docs/CAD/Gripper/3D-print/TPU/TPU-Layer-Right-Jaw.stl
7.00 x 15.0 x 104.5

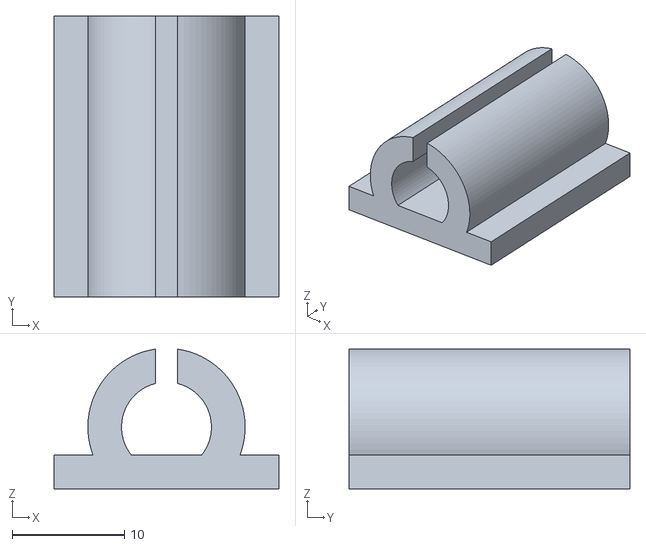
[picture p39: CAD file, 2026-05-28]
docs/CAD/Hanoi-Platform-Camera-Support/3D-print/Box/cable_management.stl
20.0 x 25.0 x 12.4

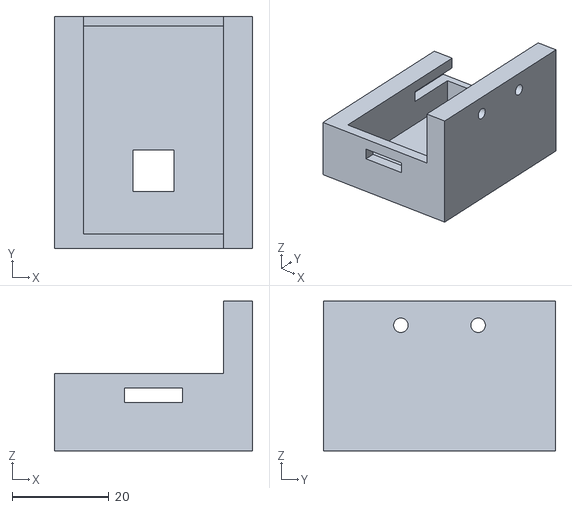
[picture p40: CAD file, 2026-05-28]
docs/CAD/Hanoi-Platform-Camera-Support/3D-print/Camera/esp_body.stl
41.0 x 48.0 x 31.0

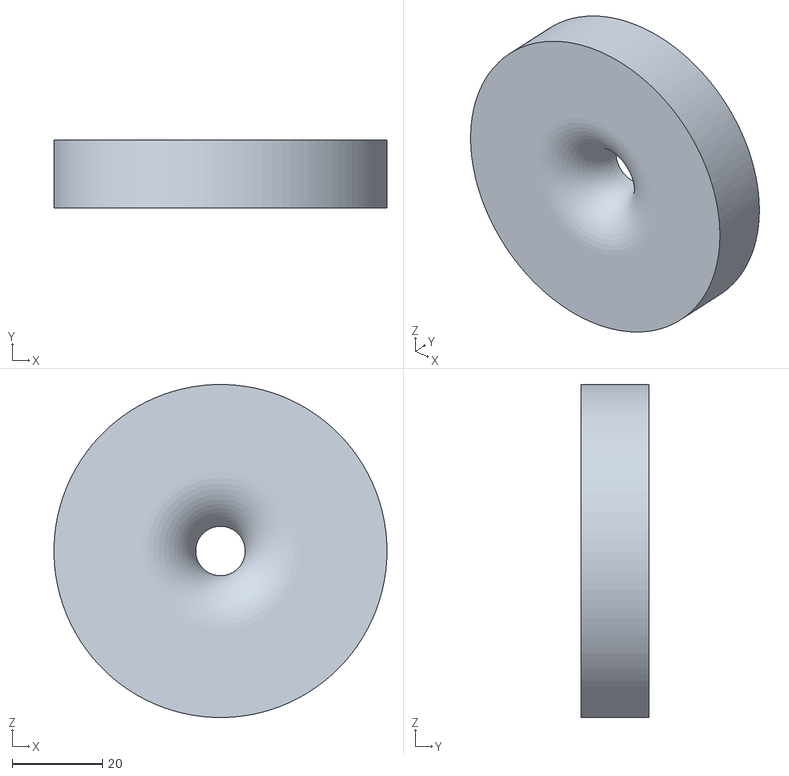
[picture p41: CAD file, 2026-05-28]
docs/CAD/Hanoi-Platform-Camera-Support/3D-print/Disks/Disk4.stl
74.0 x 15.0 x 74.0

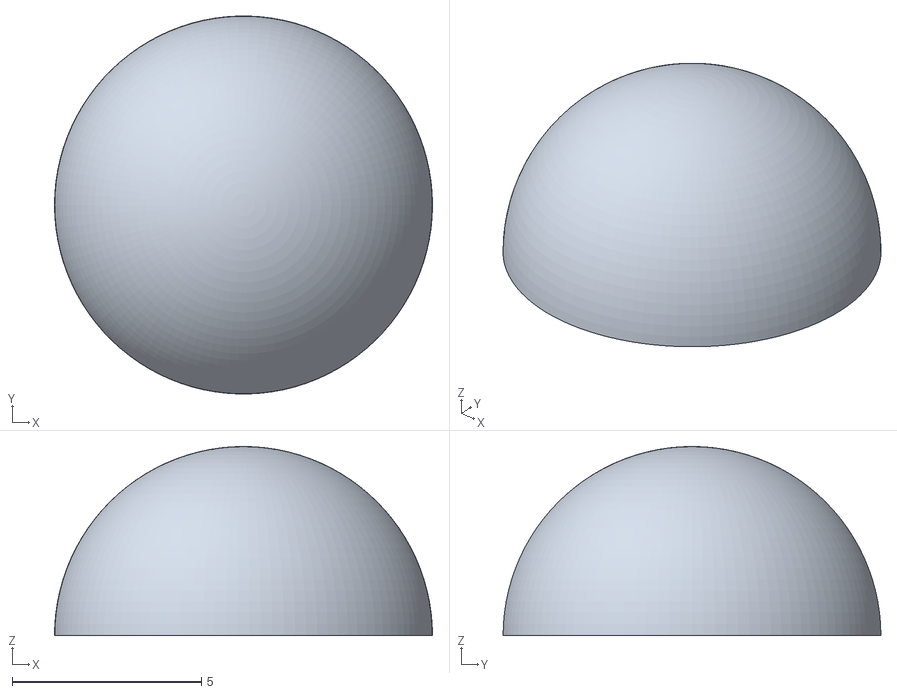
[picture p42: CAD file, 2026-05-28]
docs/CAD/Hanoi-Platform-Camera-Support/3D-print/Pegs/peg-head-top.stl
10.0 x 10.00 x 5.00

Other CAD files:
docs/CAD/Hanoi-Platform-Camera-Support/Assembly/HanoiPlatformandCameraSupport.step
docs/CAD/Hanoi-Platform-Camera-Support/Laser-cut/TopHanoiBox.dxf
docs/CAD/Arm/3D-print/inner-arm/inner-housing-cover2.stl
docs/CAD/Arm/3D-print/outer-arm/outer-pillar2.stl
docs/CAD/Arm/3D-print/inner-arm/inner-cover1.stl
docs/CAD/Arm/3D-print/inner-arm/inner-cover2.stl
docs/CAD/Arm/3D-print/inner-arm/inner-cover3.stl
docs/CAD/Arm/3D-print/inner-arm/inner-housing-cover1.stl
docs/CAD/Arm/3D-print/inner-arm/inner-housing1.stl
docs/CAD/Arm/3D-print/inner-arm/inner-housing2.stl
docs/CAD/Arm/3D-print/inner-arm/inner-pillar1.stl
docs/CAD/Arm/3D-print/inner-arm/inner-pillar3.stl
docs/CAD/Arm/3D-print/inner-arm/inner-pulley.stl
docs/CAD/Arm/3D-print/outer-arm/outer-cover2.stl
docs/CAD/Arm/3D-print/outer-arm/outer-housing-cover1.stl
docs/CAD/Arm/3D-print/outer-arm/outer-housing-cover2.stl
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

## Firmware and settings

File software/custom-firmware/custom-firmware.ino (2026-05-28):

/*
  SCARAnoi Custom RAMPS 1.4 Firmware
  Board: Arduino Mega 2560 + RAMPS 1.4
  Drivers: A4988
  Motors:
    RAMPS X driver = SCARA shoulder joint motor
    RAMPS Y driver = SCARA elbow / platform joint motor
    RAMPS Z driver = vertical Z axis
    RAMPS E0 driver = wrist / gripper rotation axis

  This is NOT Marlin.
  It implements a small Marlin-like command set for manual robot control.

  Supported commands:
    G0/G1 X.. Y.. Z.. E.. F..   Move. X/Y are Cartesian mm. Z is mm. E is logical gripper angle.
    G28 [X] [Y] [Z] [E]         Home enabled axes.
    G90                         Absolute positioning
    G91                         Relative positioning
    G92 X.. Y.. Z.. E..         Set current logical position
    M17                         Enable all motors
    M17 X / M17 Y / M17 Z / M17 E Enable selected motors only
    M18 / M84                   Disable all motors
    M18 X / M18 Y / M18 Z / M18 E Disable selected motors only
    M112                        Emergency stop, checked even during motion
    M119                        Report endstop states
    M114                        Report current position
    M211 S0/S1                  Disable/enable software limits
    M280 P0 Sangle              Move servo gripper to angle
    M281 Oangle Cangle          Set gripper open/close angles in RAM only
    M282 P0                     Detach servo
    M360 X.. Y.. Z.. E.. F..    Joint move. X/Y are joint degrees, Z is mm, E is logical gripper angle. No SCARA IK.
    M361                        Report gripper orientation mode
    M361 S0                     Independent mode: gripper keeps a fixed world direction.
    M361 S1                     Tracking mode: gripper stays fixed relative to the elbow.
    M503                        Report main settings
    M999                        Clear emergency stop

  Important:
    - X/Y G-code targets are converted to SCARA joint angles inside the firmware.
    - In normal G0/G1 moves, E is now the logical gripper angle, not the raw E motor angle.
    - In independent mode, the E motor compensates shoulder rotation only.
    - In tracking mode, the E motor compensates shoulder rotation and adds elbow rotation.
    - M360 is also subject to the selected gripper mode, so X/Y joint moves compensate E automatically.
    - The firmware uses INPUT_PULLUP for endstops.
    - For a normally-open switch wired between signal and GND, triggered = LOW.
*/

#include <Arduino.h>
#include <Servo.h>
#include <math.h>

// ================================================================
// ========================= USER SETTINGS =========================
// ================================================================

#define G_CODE_SERIAL Serial2

// Serial speed. This matches your old Marlin config.
static const long BAUDRATE = 250000;

// ------------------------- Custom Commands -------------------------
// Default values for custom text macros. Change these as needed.

static float X_START_COORD = 0.0f;
static float Y_START_COORD = 240.0f;
static float Z_START_COORD = 150.0f;
static float E_START_COORD = 0.0f;

static float X_START = 78.932f;
static float Y_START = 73.564f;
static float Z_START = 0.0f;
static float E_START = 121.711f;

static float Z_UP = -140.0f;
static float Z_LAYER1 = -232.0f;
static float Z_LAYER2 = -215.0f;
static float Z_LAYER3 = -200.0f;
static float Z_LAYER4 = -185.0f;
static float Z_LAYER5 = -170.0f;

static float X_PEG2 = 144.0f;
static float X_PEG1 = 24.0f;
static float X_PEG0 = -95.0f;

static float Y_PEG2 = 240.0f;
static float Y_PEG1 = 250.0f;
static float Y_PEG0 = 265.0f;

static float X_PEG2_UP = 144.0f;
static float X_PEG1_UP = 24.0f;
static float X_PEG0_UP = -95.0f;

static float Y_PEG2_UP = 240.0f;
static float Y_PEG1_UP = 250.0f;
static float Y_PEG0_UP = 265.0f;

static int CURRENT_PEG = 1;

// ------------------------- RAMPS 1.4 pins ------------------------
// Standard RAMPS 1.4 pin mapping for Arduino Mega.
static const uint8_t X_STEP_PIN = 54;
static const uint8_t X_DIR_PIN  = 55;
static const uint8_t X_EN_PIN   = 38;

static const uint8_t Y_STEP_PIN = 60;
static const uint8_t Y_DIR_PIN  = 61;
static const uint8_t Y_EN_PIN   = 56;

static const uint8_t Z_STEP_PIN = 46;
static const uint8_t Z_DIR_PIN  = 48;
static const uint8_t Z_EN_PIN   = 62;

static const uint8_t E_STEP_PIN = 26;
static const uint8_t E_DIR_PIN  = 28;
static const uint8_t E_EN_PIN   = 24;

// Endstop pins on RAMPS.
static const uint8_t X_MIN_PIN = 3;
static const uint8_t X_MAX_PIN = 2;
static const uint8_t Y_MIN_PIN = 14;
static const uint8_t Y_MAX_PIN = 15;
static const uint8_t Z_MIN_PIN = 18;
static const uint8_t Z_MAX_PIN = 19;

// E Endstop pins using free servo header pins.
static const uint8_t E_MIN_PIN = 5; // D5
static const uint8_t E_MAX_PIN = 4; // D4

// RAMPS servo header.
// Servo 0 is usually D11 on RAMPS 1.4.
static uint8_t SERVO_GRIPPER_PIN = 11;

// ------------------------- Motor logic ---------------------------
// A4988 enable is active LOW on RAMPS.
static const bool ENABLE_ACTIVE_LOW = true;

// Direction inversion. Change these if an axis moves the wrong way.
static bool INVERT_SHOULDER_DIR = true;  // RAMPS X driver
static bool INVERT_ELBOW_DIR    = true;  // RAMPS Y driver
static bool INVERT_Z_DIR        = false; // from your old Marlin config
static bool INVERT_E_DIR        = false; // wrist rotation

// ------------------------- Steps per unit ------------------------
// From your previous Marlin config:
//   { 88.8889, 35.5556, 400, 35.5556 }
// Here X/Y become SCARA joint degrees.
static float SHOULDER_STEPS_PER_DEG = 200*16*8 / 360; // 200 * 16 * 10/360
static float ELBOW_STEPS_PER_DEG    = 200*16*3.2 / 360;
static float Z_STEPS_PER_MM         = 200*8 / 8;
static float E_STEPS_PER_DEG        = 200*16*3.2 / 360;

// ------------------------- Speed limits --------------------------
// Conservative defaults. Increase only after testing.
static float MAX_SHOULDER_DEG_S = 140.0f;
static float MAX_ELBOW_DEG_S    = 350.0f;
static float MAX_Z_MM_S         = 40.0f;
static float MAX_E_DEG_S        = 350.0f;

static float CURRENT_SPEED = 3500.0f;
static const float SIDE_SPEED = 9000.0f;

// Minimum delay between coordinated step ticks.
// Larger = slower but safer for A4988 and mechanical testing.
static unsigned long MIN_STEP_TICK_US = 100;

// ------------------------- Acceleration --------------------------
// Simple trapezoidal acceleration profile.
// This only changes the delay between steps during a move.
static bool USE_ACCELERATION = true;

// Fraction of the move used for acceleration and deceleration.
// 0.20 means first 20% accelerates and last 20% decelerates.
static float ACCELERATION_PORTION = 0.15f;

// Start/end delay multiplier.
// 3.0 means the move starts and ends 3x slower than the target speed.
static float START_SPEED_FACTOR = 2.0f;

// Step pulse width for A4988.
// 3-5 us is normally safe.
static const unsigned int STEP_PULSE_US = 4;

// ------------------------- SCARA geometry ------------------------
// From your old Marlin config.
static float LINK_1_MM = 185.412f;
static float LINK_2_MM = 111.000f;

// Offset of the SCARA base/tower in Cartesian coordinates.
static float SCARA_OFFSET_X = 0.0f;
static float SCARA_OFFSET_Y = 0.0f;

// Joint angle offsets in degrees.
// Use these if the mathematical zero angle does not match your physical zero.
static float SHOULDER_OFFSET_DEG = 0.0f;
static float ELBOW_OFFSET_DEG    = 0.0f;

// Elbow configuration.
// +1 and -1 choose the two possible IK solutions.
// If the arm bends the wrong way, switch this.
static int SCARA_ELBOW_SIGN = -1;

// Split long Cartesian moves into small segments.
// Smaller = closer to straight XY path, but more computation.
static float CARTESIAN_SEGMENT_MM = 1.0f;

// --------------------- Gripper orientation modes -----------------
// 0 = independent mode: gripper keeps a fixed world direction.
//     Motor E = logical E - shoulder.
// 1 = tracking mode: gripper stays fixed relative to the elbow.
//     Motor E = logical E - shoulder + elbow.
// Home uses tracking mode by default.
static int GRIPPER_MODE = 1;

static const int GRIPPER_MODE_INDEPENDENT = 0;
static const int GRIPPER_MODE_TRACKING    = 1;

// If the compensation moves the gripper in the wrong direction, change this to -1.
static int GRIPPER_COMPENSATION_SIGN = 1;

// ------------------------- Work limits ---------------------------
// Defaults based on your old Marlin file.
// You can tune these later.
static float X_MIN_MM = -(185.412f + 111.000f);
static float X_MAX_MM = 295.0f;
static float Y_MIN_MM = 0.0f;
static float Y_MAX_MM = 295.0f;
static float Z_MIN_MM = 0.0f;
static float Z_MAX_MM = 250.0f;
static float E_MIN_DEG = -180.0f;
static float E_MAX_DEG = 180.0f;

// Reach limits.
static float FORBIDDEN_RADIUS_MM = 35.0f;

// Software limits can be toggled with M211.
static bool SOFTWARE_LIMITS_ENABLED = false;

// ------------------------- Endstops ------------------------------
// Enable/disable each plug here.
// Since some of yours are connected but broken, keep them easy to disable.
static bool USE_X_MIN_ENDSTOP = true;
static bool USE_X_MAX_ENDSTOP = true;

static bool USE_Y_MIN_ENDSTOP = true;
static bool USE_Y_MAX_ENDSTOP = true;

static bool USE_Z_MIN_ENDSTOP = true;
static bool USE_Z_MAX_ENDSTOP = true;

static bool USE_E_MIN_ENDSTOP = true;
static bool USE_E_MAX_ENDSTOP = true;

// For normally-open switch wired between signal and GND with INPUT_PULLUP:
// triggered = LOW.
static bool ENDSTOP_TRIGGERED_STATE_LOW = true;

// Debounce only happens after a pin first looks triggered.
// This helps against the random emergency stops caused by very short noise spikes.
static const int ENDSTOP_DEBOUNCE_READS = 3;
static const unsigned int ENDSTOP_DEBOUNCE_US = 80;

// During normal movement, abort if an enabled endstop is triggered.
// For debugging broken endstops, set this false.
static bool HARD_ENDSTOP_ABORT_ON_TRIGGER = true;

// ------------------------- Homing -----------------------------
static int SHOULDER_HOME_DIR = -1;
static int ELBOW_HOME_DIR    = -1;
static int Z_HOME_DIR        = 1;
static int E_HOME_DIR        = -1;

// Position assigned after homing.
// These are important because they define where the robot thinks it is.
// Defaults chosen to match your old Marlin home position:
//   X = -(L1 + L2), Y = 0
// which corresponds roughly to shoulder = 180°, elbow = 0°.
static float SHOULDER_HOME_DEG = -78.932f;
static float ELBOW_HOME_DEG    = -73.564f;
static float Z_HOME_MM         = 0.0f;
static float E_HOME_DEG        = -121.675f;



// This is the raw E motor angle after E homing.
// The reported logical E is computed from this and the current gripper mode.

// Homing speeds.
static float SHOULDER_HOME_DEG_S = 40.0f;
static float ELBOW_HOME_DEG_S    = 40.0f;
static float Z_HOME_MM_S         = 20.0f;
static float E_HOME_DEG_S        = 40.0f;

// Homing travel limits.
// If no endstop triggers after this much movement, homing fails.
static float SHOULDER_HOME_MAX_TRAVEL_DEG = 360.0f;
static float ELBOW_HOME_MAX_TRAVEL_DEG    = 360.0f;
static float Z_HOME_MAX_TRAVEL_MM         = 300.0f;
static float E_HOME_MAX_TRAVEL_DEG        = 360.0f;

// Backoff after endstop trigger.
static float SHOULDER_HOME_BACKOFF_DEG = 3.0f;
static float ELBOW_HOME_BACKOFF_DEG    = 3.0f;
static float Z_HOME_BACKOFF_MM         = 3.0f;
static float E_HOME_BACKOFF_DEG        = 3.0f;

// ------------------------- Servo gripper -------------------------
static int SERVO_OPEN_ANGLE  = 150;
static int SERVO_CLOSE_ANGLE1 = 120;
static int SERVO_CLOSE_ANGLE2 = 100;
static int SERVO_CLOSE_ANGLE3 = 80;
static int SERVO_CLOSE_ANGLE4 = 60;
static int SERVO_CLOSE_ANGLE5 = 40;
static int SERVO_MIN_ANGLE   = 0;
static int SERVO_MAX_ANGLE   = 270;

// ================================================================
// ======================= INTERNAL STATE ==========================
// ================================================================

struct AxisPins {
  uint8_t stepPin;
  uint8_t dirPin;
  uint8_t enPin;
  bool invertDir;
};

AxisPins shoulderAxis = { X_STEP_PIN, X_DIR_PIN, X_EN_PIN, false };
AxisPins elbowAxis    = { Y_STEP_PIN, Y_DIR_PIN, Y_EN_PIN, false };
AxisPins zAxis        = { Z_STEP_PIN, Z_DIR_PIN, Z_EN_PIN, true  };
AxisPins eAxis        = { E_STEP_PIN, E_DIR_PIN, E_EN_PIN, false };

struct Position {
  float x;
  float y;
  float z;
  float e;
  float eMotorDeg;
  float shoulderDeg;
  float elbowDeg;
};

Position current = {
  -(185.412f + 111.000f), 0.0f, 0.0f, 0.0f, 0.0f,
  180.0f, 0.0f
};

long shoulderSteps = 0;
long elbowSteps = 0;
long zSteps = 0;
long eSteps = 0;

bool absoluteMode = true;
bool motorsEnabled = false;
bool shoulderMotorEnabled = false;
bool elbowMotorEnabled = false;
bool zMotorEnabled = false;
bool eMotorEnabled = false;
bool emergencyStopped = false;

static const int MAX_CMD_LENGTH = 127;
char inputLine[MAX_CMD_LENGTH + 1];
int inputPos = 0;

char emergencyBuffer[16];
int emergencyPos = 0;

Servo gripperServo;
bool gripperAttached = false;

// ================================================================
// ======================= UTILITY HELPERS =========================
// ================================================================

bool hasParam(const String &line, char code);
float getParam(const String &line, char code, float fallback);

float degToRad(float deg) {
  return deg * PI / 180.0f;
}

float radToDeg(float rad) {
  return rad * 180.0f / PI;
}

float clampFloat(float value, float low, float high) {
  if (value < low) return low;
  if (value > high) return high;
  return value;
}

bool approximatelyZero(float v) {
  return fabs(v) < 0.0001f;
}

void printOk() {
  G_CODE_SERIAL.println(F("ok"));
}

void printError(const __FlashStringHelper *msg) {
  G_CODE_SERIAL.print(F("error: "));
  G_CODE_SERIAL.println(msg);
}

void updateGlobalMotorState() {
  motorsEnabled = shoulderMotorEnabled || elbowMotorEnabled || zMotorEnabled || eMotorEnabled;
}

void enableMotorByLetter(char axis) {
  uint8_t active = ENABLE_ACTIVE_LOW ? LOW : HIGH;

  if (axis == 'X') {
    digitalWrite(X_EN_PIN, active);
    shoulderMotorEnabled = true;
  } else if (axis == 'Y') {
    digitalWrite(Y_EN_PIN, active);
    elbowMotorEnabled = true;
  } else if (axis == 'Z') {
    digitalWrite(Z_EN_PIN, active);
    zMotorEnabled = true;
  } else if (axis == 'E') {
    digitalWrite(E_EN_PIN, active);
    eMotorEnabled = true;
  }

  updateGlobalMotorState();
}

void disableMotorByLetter(char axis) {
  uint8_t inactive = ENABLE_ACTIVE_LOW ? HIGH : LOW;

  if (axis == 'X') {
    digitalWrite(X_EN_PIN, inactive);
    shoulderMotorEnabled = false;
  } else if (axis == 'Y') {
    digitalWrite(Y_EN_PIN, inactive);
    elbowMotorEnabled = false;
  } else if (axis == 'Z') {
    digitalWrite(Z_EN_PIN, inactive);
    zMotorEnabled = false;
  } else if (axis == 'E') {
    digitalWrite(E_EN_PIN, inactive);
    eMotorEnabled = false;
  }

  updateGlobalMotorState();
}

void enableMotors() {
  enableMotorByLetter('X');
  enableMotorByLetter('Y');
  enableMotorByLetter('Z');
  enableMotorByLetter('E');
}

void disableMotors() {
  disableMotorByLetter('X');
  disableMotorByLetter('Y');
  disableMotorByLetter('Z');
  disableMotorByLetter('E');
}

void enableMotorsFromCommand(const String &line) {
  bool hasAxis = hasParam(line, 'X') || hasParam(line, 'Y') || hasParam(line, 'Z') || hasParam(line, 'E');

  if (!hasAxis) {
    enableMotors();
    return;
  }

  if (hasParam(line, 'X')) enableMotorByLetter('X');
  if (hasParam(line, 'Y')) enableMotorByLetter('Y');
  if (hasParam(line, 'Z')) enableMotorByLetter('Z');
  if (hasParam(line, 'E')) enableMotorByLetter('E');
}

void disableMotorsFromCommand(const String &line) {
  bool hasAxis = hasParam(line, 'X') || hasParam(line, 'Y') || hasParam(line, 'Z') || hasParam(line, 'E');

  if (!hasAxis) {
    disableMotors();
    return;
  }

  if (hasParam(line, 'X')) disableMotorByLetter('X');
  if (hasParam(line, 'Y')) disableMotorByLetter('Y');
  if (hasParam(line, 'Z')) disableMotorByLetter('Z');
  if (hasParam(line, 'E')) disableMotorByLetter('E');
}

void setDirection(const AxisPins &axis, int dirSign) {
  bool positive = dirSign >= 0;
  bool level = positive ^ axis.invertDir;
  digitalWrite(axis.dirPin, level ? HIGH : LOW);
}

void stepAxis(const AxisPins &axis) {
  digitalWrite(axis.stepPin, HIGH);
  delayMicroseconds(STEP_PULSE_US);
  digitalWrite(axis.stepPin, LOW);
}

bool rawPinTriggered(uint8_t pin) {
  int value = digitalRead(pin);
  if (ENDSTOP_TRIGGERED_STATE_LOW) return value == LOW;
  return value == HIGH;
}

bool pinTriggered(uint8_t pin) {
  if (!rawPinTriggered(pin)) return false;

  for (int i = 0; i < ENDSTOP_DEBOUNCE_READS; i++) {
    delayMicroseconds(ENDSTOP_DEBOUNCE_US);
    if (!rawPinTriggered(pin)) return false;
  }

  return true;
}

bool xMinTriggered() { return USE_X_MIN_ENDSTOP && pinTriggered(X_MIN_PIN); }
bool xMaxTriggered() { return USE_X_MAX_ENDSTOP && pinTriggered(X_MAX_PIN); }
bool yMinTriggered() { return USE_Y_MIN_ENDSTOP && pinTriggered(Y_MIN_PIN); }
bool yMaxTriggered() { return USE_Y_MAX_ENDSTOP && pinTriggered(Y_MAX_PIN); }
bool zMinTriggered() { return USE_Z_MIN_ENDSTOP && pinTriggered(Z_MIN_PIN); }
bool zMaxTriggered() { return USE_Z_MAX_ENDSTOP && pinTriggered(Z_MAX_PIN); }
bool eMinTriggered() { return USE_E_MIN_ENDSTOP && pinTriggered(E_MIN_PIN); }
bool eMaxTriggered() { return USE_E_MAX_ENDSTOP && pinTriggered(E_MAX_PIN); }

const char *firstTriggeredEndstopName() {
  if (xMinTriggered()) return "x_min";
  if (xMaxTriggered()) return "x_max";
  if (yMinTriggered()) return "y_min";
  if (yMaxTriggered()) return "y_max";
  if (zMinTriggered()) return "z_min";
  if (zMaxTriggered()) return "z_max";
  if (eMinTriggered()) return "e_min";
  if (eMaxTriggered()) return "e_max";
  return NULL;
}

bool anyEnabledEndstopTriggered() {
  return firstTriggeredEndstopName() != NULL;
}

float gripperCompensationFor(float shoulderDeg, float elbowDeg) {
  float compensation = 0;

  if (GRIPPER_MODE == GRIPPER_MODE_TRACKING) {
    compensation += elbowDeg;
  } else {
    compensation -= shoulderDeg;
  }

  return compensation * (float)GRIPPER_COMPENSATION_SIGN;
}

float logicalToMotorE(float logicalE, float shoulderDeg, float elbowDeg) {
  return logicalE + gripperCompensationFor(shoulderDeg, elbowDeg);
}

float motorToLogicalE(float motorE, float shoulderDeg, float elbowDeg) {
  return motorE - gripperCompensationFor(shoulderDeg, elbowDeg);
}

void emergencyStop(const __FlashStringHelper *reason) {
  emergencyStopped = true;
  disableMotors();

  G_CODE_SERIAL.print(F("error: emergency stop"));
  if (reason) {
    G_CODE_SERIAL.print(F(" - "));
    G_CODE_SERIAL.print(reason);
  }
  G_CODE_SERIAL.println();
}

void emergencyStopEndstop(const char *name) {
  emergencyStopped = true;
  disableMotors();

  G_CODE_SERIAL.print(F("error: emergency stop - enabled endstop triggered during movement"));
  if (name) {
    G_CODE_SERIAL.print(F(": "));
    G_CODE_SERIAL.print(name);
  }
  G_CODE_SERIAL.println();
}

void updateStepCountersFromPosition() {
  shoulderSteps = lround(current.shoulderDeg * SHOULDER_STEPS_PER_DEG);
  elbowSteps    = lround(current.elbowDeg    * ELBOW_STEPS_PER_DEG);
  zSteps        = lround(current.z           * Z_STEPS_PER_MM);
  eSteps        = lround(current.eMotorDeg   * E_STEPS_PER_DEG);
}

void forwardKinematics(float shoulderDeg, float elbowDeg, float &x, float &y) {
  float theta = degToRad(shoulderDeg - SHOULDER_OFFSET_DEG);
  float psi   = degToRad(elbowDeg - ELBOW_OFFSET_DEG);

  y = SCARA_OFFSET_Y + LINK_1_MM * cos(theta) + LINK_2_MM * cos(theta + psi);
  x = SCARA_OFFSET_X + LINK_1_MM * sin(theta) + LINK_2_MM * sin(theta + psi);
}

bool inverseKinematics(float x, float y, float &shoulderDeg, float &elbowDeg) {
  float px = x - SCARA_OFFSET_X;
  float py = y - SCARA_OFFSET_Y;

  float r2 = px * px + py * py;
  float r = sqrt(r2);

  float maxReach = LINK_1_MM + LINK_2_MM;
  float minReach = fabs(LINK_1_MM - LINK_2_MM);

  /*if (r > maxReach + 0.001f) return false;
  if (r < minReach - 0.001f) return false;
  if (r < FORBIDDEN_RADIUS_MM) return false;*/

  float c2 = (r2 - LINK_1_MM * LINK_1_MM - LINK_2_MM * LINK_2_MM) / (2.0f * LINK_1_MM * LINK_2_MM);
  c2 = clampFloat(c2, -1.0f, 1.0f);

  float s2 = SCARA_ELBOW_SIGN * sqrt(max(0.0f, 1.0f - c2 * c2));
  float psi = atan2(s2, c2);

  float theta = atan2(px, py) - atan2(LINK_2_MM * s2, LINK_1_MM + LINK_2_MM * c2);

  shoulderDeg = radToDeg(theta) + SHOULDER_OFFSET_DEG;
  elbowDeg = radToDeg(psi) + ELBOW_OFFSET_DEG;

  return true;
}
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
void loop() {
  while (G_CODE_SERIAL.available() > 0) {
    char c = (char)G_CODE_SERIAL.read();
    Serial.print(c);

    if (c == '\r') continue;

    if (c == '\n') {
      inputLine[inputPos] = '\0';
      String line(inputLine);
      inputPos = 0;
      memset(inputLine, 0, MAX_CMD_LENGTH + 1);
      
      handleCommand(line);
    } else if (inputPos < MAX_CMD_LENGTH) {
      inputLine[inputPos++] = c;

      // Early emergency detection
      if (inputPos >= 4) {
        if (strstr(inputLine, "M112") || strstr(inputLine, "m112")) {
          inputPos = 0;
          memset(inputLine, 0, MAX_CMD_LENGTH + 1);
          emergencyStop(F("M112 received"));
        }
      }
    } else {
      inputPos = 0;
      memset(inputLine, 0, MAX_CMD_LENGTH + 1);
      printError(F("command too long"));
    }
  }
}

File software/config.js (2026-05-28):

const CONFIG = {
  espIp: localStorage.getItem("scaranoiEspIp") || "172.21.76.162",

  // Python OpenCV bridge. It still runs locally for camera processing/CV.
  cvServerUrl: localStorage.getItem("scaranoiCvServerUrl") || "http://localhost:5000",

  // Robot commands are now sent to the ESP32 HTTP bridge, not to the computer/USB bridge.
  // The control URL is derived from espIp in getControlBaseUrl().

  arm: {
    link1: 185.412,
    link2: 111.000,
    forbiddenRadius: 35,
    displayScale: 0.55
  },

  hanoi: {
    maxDisks: 5,
    // Keep this false if you want to solve partial/variant setups such as [5 4 3].
    requireExactDiskCount: false,
    numDisks: 5,
    // After each completed disk transfer, capture CV again and compare it with the expected state.
    verifyAfterEachMove: true,
    targetPegWhenNotSolved: 2,
    targetPegWhenAlreadyOnRight: 0,
    // With M400/M114 sync, this only needs to be a short camera-settle delay.
    verifyDelayMs: 300,
    // Small UI gap between substeps. The solver now waits for firmware ok on each substep.
    autoStepDelayMs: 50,
    // Max time to wait for one Hanoi physical substep to finish and acknowledge.
    substepTimeoutSeconds: 45,
    // START is a firmware macro that currently prints more than one ok.
    // The ESP bridge waits for this many ok lines before the UI continues.
    startOkCount: 2,
    startTimeoutSeconds: 90,
    // After START, do not immediately run M400/M114. START already moved the arm
    // and old firmware output can still be flushing; syncing here can make M114 timeout.
    syncAfterStart: false,
    completionSyncCommand: "M400\nM114",
    completionTimeoutSeconds: 45,

    // Real peg centers used for drawing the yellow peg markers.
    firmwarePegs: [
      { name: "PEG0", x: -100, y: 275 },
      { name: "PEG1", x: 18,   y: 275 },
      { name: "PEG2", x: 145,  y: 275 }
    ],

    // Coordinates reached by the firmware PEG0/PEG1/PEG2 macros at Z_UP.
    // These should match X_PEG*_UP / Y_PEG*_UP in the Arduino firmware.
    firmwarePegUpPositions: [
      { name: "PEG0", x: -95, y: 275 },
      { name: "PEG1", x: 22,  y: 265 },
      { name: "PEG2", x: 140, y: 258 }
    ],

    firmwareCommands: {
      start: "START",
      up: "UP",
      open: "OPEN",
      close: "CLOSE1",
      pegCommandsByIndex: ["PEG0", "PEG1", "PEG2"],
      layerPrefix: "LAYER"
    },

    firmwareServo: {
      openAngle: 120,
      closeAngle: 0
    }
  },

  axes: {
    x: "X",
    y: "Y",
    z: "Z",
    wrist: "E"
  },

  gripper: {
    detach: "M282 P0"
  },

  system: {
    home: "G28",
    getPosition: "M114",
    checkEndstops: "M119",
    enableMotors: "M17",
    disableMotors: "M18",
    emergencyStop: "M112",
    // Home can be slow. This is only a maximum safety timeout; M114 is sent
    // immediately after G28 returns ok, not after a fixed delay.
    homeTimeoutSeconds: 120,
    positionSyncTimeoutSeconds: 10
  }
};

function setEspIp(ip) {
  const clean = String(ip || "").trim().replace(/^https?:\/\//, "").replace(/\/$/, "");
  if (!clean) return false;
  CONFIG.espIp = clean;
  localStorage.setItem("scaranoiEspIp", clean);
  return true;
}

function getControlBaseUrl() {
  return `http://${CONFIG.espIp}`;
}

function getStreamUrl() {
  return `http://${CONFIG.espIp}:81/stream`;
}

function getCaptureUrl() {
  return `http://${CONFIG.espIp}/capture`;
}

function getCvServerBaseUrl() {
  const clean = String(CONFIG.cvServerUrl || "").trim().replace(/\/$/, "");
  return clean || "http://localhost:5000";
}

function getCvStreamUrl() {
  return `${getCvServerBaseUrl()}/cv-stream`;
}

function getCvSnapshotUrl() {
  return `${getCvServerBaseUrl()}/cv-snapshot`;
}

function getCvDetectUrl() {
  return `${getCvServerBaseUrl()}/detect`;
}

function getCvSetEspUrl() {
  return `${getCvServerBaseUrl()}/set-esp?ip=${encodeURIComponent(CONFIG.espIp)}`;
}

function unitsPerSecondToFeedrate(unitsPerSecond) {
  return Number(unitsPerSecond) * 60;
}

function formatNumber(value) {
  return Number(value).toFixed(2).replace(/\.?0+$/, "");
}

function buildRelativeMove(axis, delta, feedrate) {
  return `G91\nG1 ${axis}${formatNumber(delta)} F${feedrate}\nG90`;
}

function buildAbsoluteMove(coords, feedrate) {
  const parts = [];

  if (coords.x !== "" && coords.x !== null && coords.x !== undefined) {
    parts.push(`${CONFIG.axes.x}${formatNumber(coords.x)}`);
  }

  if (coords.y !== "" && coords.y !== null && coords.y !== undefined) {
    parts.push(`${CONFIG.axes.y}${formatNumber(coords.y)}`);
  }

  if (coords.z !== "" && coords.z !== null && coords.z !== undefined) {
    parts.push(`${CONFIG.axes.z}${formatNumber(coords.z)}`);
  }

  if (coords.e !== "" && coords.e !== null && coords.e !== undefined) {
    parts.push(`${CONFIG.axes.wrist}${formatNumber(coords.e)}`);
  }

  if (parts.length === 0) return null;

  return `G90\nG1 ${parts.join(" ")} F${feedrate}`;
}
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

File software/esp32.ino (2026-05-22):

#include "esp_camera.h"
#include <WiFi.h>
#include <WebServer.h>

// Set to true only while debugging the camera stream.
// Keeping this false avoids slow Serial prints on every video frame.
#define STREAM_DEBUG false

// ================================================================
// ========================= NETWORK MODE ==========================
// ================================================================

// true  = ESP creates its own Wi-Fi network, like the old working code.
// false = ESP connects to your hotspot/router as a normal Wi-Fi client.
#define USE_SOFT_AP false

// SoftAP credentials, used when USE_SOFT_AP = true.
const char* AP_SSID = "SCARAnoi";
const char* AP_PASSWORD = "12345678";

// Station credentials, used when USE_SOFT_AP = false.
const char* STA_SSID = "SPOT-iot";
const char* STA_PASSWORD = "CurieuseAdjointFondante5449";

// ================================================================
// ========================= WEB SERVERS ===========================
// ================================================================

WebServer controlServer(80);
WiFiServer streamServer(81);

// ================================================================
// =================== Arduino serial bridge =======================
// ================================================================

#define ARDUINO_RX_PIN 13  // ESP RX: connect to Arduino Mega TX2 pin 16
#define ARDUINO_TX_PIN 14  // ESP TX: connect to Arduino Mega RX2 pin 17
#define ARDUINO_BAUD 250000
HardwareSerial arduinoSerial(2);

static const unsigned long COMMAND_TIMEOUT_MS = 120000;
static const unsigned long RESPONSE_SETTLE_MS = 80;

// ================================================================
// ================= ESP32-CAM AI Thinker pins =====================
// ================================================================

#define PWDN_GPIO_NUM     32
#define RESET_GPIO_NUM    -1
#define XCLK_GPIO_NUM      0
#define SIOD_GPIO_NUM     26
#define SIOC_GPIO_NUM     27

#define Y9_GPIO_NUM       35
#define Y8_GPIO_NUM       34
#define Y7_GPIO_NUM       39
#define Y6_GPIO_NUM       36
#define Y5_GPIO_NUM       21
#define Y4_GPIO_NUM       19
#define Y3_GPIO_NUM       18
#define Y2_GPIO_NUM        5
#define VSYNC_GPIO_NUM    25
#define HREF_GPIO_NUM     23
#define PCLK_GPIO_NUM     22

// ================================================================
// =========================== Helpers =============================
// ================================================================

void sendCorsHeaders() {
  controlServer.sendHeader("Access-Control-Allow-Origin", "*");
  controlServer.sendHeader("Access-Control-Allow-Methods", "GET, OPTIONS");
  controlServer.sendHeader("Access-Control-Allow-Headers", "*");
}

void handleOptions() {
  sendCorsHeaders();
  controlServer.send(204);
}

String cleanCommandLine(String raw) {
  int semicolon = raw.indexOf(';');
  if (semicolon >= 0) raw = raw.substring(0, semicolon);

  raw.replace("\r", "");
  raw.trim();
  return raw;
}

bool isFirmwareOkLine(String line) {
  line.trim();
  line.toLowerCase();
  return line == "ok" || line.startsWith("ok ") || line.endsWith(" ok");
}

bool isFirmwareErrorLine(String line) {
  line.trim();
  line.toLowerCase();
  return line.startsWith("error") || line.startsWith("fatal");
}

bool lineContainsPositionReport(String line) {
  line.toUpperCase();
  return line.indexOf("X:") >= 0 && line.indexOf("Y:") >= 0;
}

bool queryValueLooksTrue(String value, bool defaultValue) {
  if (value.length() == 0) return defaultValue;
  value.trim();
  value.toLowerCase();
  return value == "1" || value == "true" || value == "yes" || value == "on" || value == "ok";
}

unsigned long queryTimeoutMs(unsigned long fallbackMs) {
  if (!controlServer.hasArg("timeout")) return fallbackMs;

  float seconds = controlServer.arg("timeout").toFloat();
  if (seconds <= 0.0f) return fallbackMs;

  unsigned long timeoutMs = (unsigned long)(seconds * 1000.0f);
  if (timeoutMs < 500) timeoutMs = 500;
  if (timeoutMs > 120000) timeoutMs = 120000;
  return timeoutMs;
}

static const int REPLY_OK = 0;
static const int REPLY_ERROR = 1;
static const int REPLY_TIMEOUT = 2;

String firmwareStatusName(int status) {
  if (status == REPLY_OK) return "ok";
  if (status == REPLY_ERROR) return "error";
  return "timeout";
}
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

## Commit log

2026-05-22 feat: integrate control interface, CV, and Hanoi workflow
    This work is grouped into one PR because the software parts were originally developed in separate branches but are strongly linked in the final system. Instead of merging each branch separately and risking broken intermediate states, I regrouped the different parts into one integration PR before starting my work on the integration.
    Overall additions:
    - Added the full SCARAnoi browser interface
    - Added OpenCV integration to the interface for disk detection
    - Added Hanoi state reconstruction from the detected disks
    - Added the Hanoi solving flow
    - Added move execution logic for transferring disks between pegs
    - Added command generati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
    [app.js, config.js, cv_server.py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]
2026-05-27 feat: add scara arm firmware (#47)
2026-05-28 added-human-play-mode (#49)
    * feat: remove pink, add support to closeX commands
    * feat: updated detection
    * feat: revert hanoi back
    * fix: change roi_bottom_pct
    * feat: new peg value bounds
    * new software with disk green biggest and human mode
    * added human play mode with error detection
    ---------
    [config.js, detectDisque.py, hanoi-solver.js]
2026-05-28 feat: fix software code layout (#50)
    [axis-center.ino, custom-firmware.ino]
2026-05-28 feat: add readme
    * Add README structure
    Added the initial README structure for the SCARAnoi project, including the project overview, build instructions, hardware sections, electronics, software, motion, computer vision, Hanoi algorithm, autonomous operation, manual control, bill of materials, and risk assessment.
    Some file links, images, dimensions, and final implementation details still need to be completed.
    * Corrected gripper and disk specifications
    * feat: improve layout
    * feat: add contributors
    * feat: add base paragraph
    * feat: shorten paragraphs and fix layout
    * feat: add software outline
    * feat: add images base
    * feat: add interface images
    * feat: attempt to fix the imag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
    [BigSideHanoiBox.dxf, BotBox.dxf, BotElec.dxf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]
2026-05-28 feat: added images gripper (#52)
2026-05-28 fix: revert previous interface code
    [hanoi-solver.js]
2026-05-28 feat: add gripper image
